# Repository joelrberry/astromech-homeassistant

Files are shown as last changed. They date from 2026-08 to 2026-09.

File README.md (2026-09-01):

# droidrefit — an offline-first astromech droid

Custom MicroPython firmware for a stationary R2-D2 display build. It runs
**standalone** — three front-panel buttons drive the dome servo, sound, and
dome lights (tap mode ▲ / ▼ to cycle reactions, hold to adjust volume, tap
sound for a clip), with a piezo buzzer for feedback. WiFi + **Home Assistant**
(pick a reaction from a dashboard) are an optional layer, off by default; hold
**Mode ▲ + Sound** ~5 s to set up WiFi. No RC transmitter.

> **Repo name is historical.** This started as a firmware swap on a *CyberBrick*
> ESP32-C3 core board. That board browned out under servo + NeoPixels + WiFi,
> so the project moved to a plain **ESP32** with an external 5 V supply and a
> from-scratch modular firmware. The reverse-engineering writeup from that first
> chapter is [docs/cyberbrick-origins.md](docs/cyberbrick-origins.md).

## What's here

| Path | What |
|---|---|
| [`droidrefit/`](droidrefit/) | the firmware — `app/` package, `lib/`, `boot.py`, `main.py`, `package.json` (OTA manifest) |
| [`tools/deploy.py`](tools/deploy.py) | one-command host→board sync (`mpremote`), also the initial-load tool |
| [`hardware/droidrefit-pcb/`](hardware/droidrefit-pcb/) | KiCad carrier board — sockets the ESP32 devkit + DFPlayer, one 5 V rail, USB-C in. [DESIGN.md](hardware/droidrefit-pcb/DESIGN.md) |
| [`docs/firmware.md`](docs/firmware.md) | **the firmware reference** — architecture, boot flow, control surfaces, OTA, recovery |
| [`docs/dfplayer.md`](docs/dfplayer.md) | DFPlayer Mini — SD-card layout, adding sound clips, the serial protocol |
| [`docs/cyberbrick-origins.md`](docs/cyberbrick-origins.md) | the original CyberBrick writeup (retired board, but the LED/MQTT approach carried forward) |
| [`docs/project-notes.md`](docs/project-notes.md) | running history — decisions, bugs found and fixed |

## Hardware (as-built)

Plain ESP32 devkit · one dome servo (GPIO18) · DFPlayer Mini + speaker
(GPIO16/17, BUSY GPIO4) · 4× WS2812 dome lights (GPIO5, via a `74AHCT1G125`
level shifter) · 3 buttons (GPIO32/33/25, pin↔GND) · piezo buzzer (GPIO27) ·
optional SSD1306 OLED (I2C, GPIO21/22) · a shared **5 V, 3 A+**
rail everything hangs off directly. The
[carrier PCB](hardware/droidrefit-pcb/DESIGN.md) (100×70 mm, USB-C in,
JLCPCB-assembled) makes that permanent; a breadboard works for bench work if
you power the ESP32 over its own USB.

## Quick start

```
pip install mpremote
python3 tools/deploy.py --wipe
```

`deploy.py` stages the copy in safe mode and SHA-verifies every file, retrying
over a flaky USB link; a failed run leaves the board at a safe REPL, and
re-running converges. `--stay` leaves it in safe mode; `--format` reformats
the flash (last resort).

> **After flashing, hard power-cycle the board** (pull power / press EN — not
> just a soft reset). `deploy.py` ends with a soft reset, but hardware timers,
> the UART, PWM, and singleton driver objects survive that; only a cold boot
> gives the clean state the firmware actually runs in.

It boots straight into the app, **offline**. Buttons: **tap** mode ▲ / ▼ to
cycle the 7 reactions, **hold** to raise / lower volume, tap Sound for a clip.
The buzzer beeps to confirm.

**To add Home Assistant:** hold **Mode ▲ + Sound** together ~5 s → the board
reboots into a WiFi AP **`R2-D2-XXXX`**. Join it from a phone, the setup page
opens, enter WiFi + a droid name (tick "Connect to Home Assistant" for the MQTT
broker fields), save. It reboots onto your network and HA auto-discovers it
over MQTT (Mode / Sound / Volume + diagnostic sensors). No always-on web panel;
the portal exits on its own after 5 min idle, or via its Cancel link.

**Updates go over USB** — after an edit, `python3 tools/deploy.py`. On-device
OTA exists but is opt-in, needs `network_enabled`, and — on a classic ESP32 —
a plain-HTTP LAN mirror (`ota_url`), because it can't TLS to GitHub while the
app runs. Detail in [docs/firmware.md](docs/firmware.md).

## Recovery

- `noboot.txt` at the flash root → boot straight to a clean REPL (`deploy.py` uses this)
- hold **Mode ▲ + Sound** ~5 s → reboot into the WiFi setup portal (auto-exits after 5 min idle)
- hold the ESP32 BOOT button ~10 s while running → factory reset (wipe config, reboot to portal)
- a crash-looping OTA build auto-rolls-back after 3 failed boots

## Credits

- **The droid** — [*Build-A-Droid: CyberBrick based robot kit*](https://makerworld.com/en/models/1549117-build-a-droid-cyberbrick-based-robot-kit)
  by **Neebick** on MakerWorld. That's the printed astromech this firmware
  drives; this repo is only the electronics + software, not the model.
  Licensed Creative Commons (see the model page for the exact variant and
  follow its attribution / non-commercial / share-alike terms).
- **`droidrefit/lib/umqtt/simple.py`** — vendored **unmodified** from
  [micropython-lib](https://github.com/micropython/micropython-lib/blob/master/micropython/umqtt.simple/umqtt/simple.py)
  (MIT). MicroPython ships no MQTT client.
- **`droidrefit/lib/dfplayer.py`** — a minimal DFPlayer Mini (YX5200) UART
  driver written for this project; the frame/checksum protocol is per the
  DFPlayer Mini datasheet and the widely-published community command tables,
  not copied from a specific library.
- **`droidrefit/lib/ssd1306.py`** — vendored from
  [micropython-lib](https://github.com/micropython/micropython-lib/blob/master/micropython/drivers/display/ssd1306/ssd1306.py)
  (MIT), SPI variant trimmed off.
- **[MicroPython](https://micropython.org/)** (MIT) — the runtime.
- The earlier CyberBrick chapter leaned on CyberBrick's own `/bbl` driver
  library — see [docs/cyberbrick-origins.md](docs/cyberbrick-origins.md#acknowledgments).

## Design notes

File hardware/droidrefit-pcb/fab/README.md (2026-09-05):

# droidrefit carrier PCB — fab package

Regenerated 2026-08-30 (USB-C power input; silkscreen labels de-overlapped).
2-layer, 100 × 70 mm, rounded
corners (r=3 mm), 4× M3 mounting holes. **DRC: 0 errors.**

## Order the bare board

Upload **`droidrefit-pcb-gerbers.zip`** (RS-274X gerbers + Excellon drill).

| Setting | Value |
|---|---|
| Layers | 2 |
| Dimensions | 100 × 70 mm |
| Thickness | 1.6 mm |
| Min track / clearance | 0.25 mm / 0.15 mm (well within any fab's spec) |
| Min drill | 0.3 mm |
| Copper | GND pour both layers, solid pad connection, ~32 stitching vias |

## SMD assembly (JLCPCB "Assembly")

Upload:
- **`droidrefit-pcb-BOM-JLC.csv`** — 14 line items, 20 designators
- **`droidrefit-pcb-CPL-JLC.csv`** — 20 placements, all top side

Every designator in the BOM matches one in the CPL and vice-versa (20 each).
The BOM lists designators comma-separated, **not** as ranges — JLC's parser
rejects `C5-C9` and wants `C5,C6,C7,C8,C9`. If you ever re-export from KiCad,
re-expand any ranges before uploading.
New since the first order: R8 (100 Ω, C22775), R9/R10 (4.7 kΩ, C23162) —
both JLC Basic parts, no extended fee.

This BOM/CPL is sized for JLC's **Economic PCBA** (no per-side setup fee).
Includes **J1, the USB-C receptacle** (SMD with 4 through-hole anchor posts —
JLC assembles these routinely). Basic parts: the 4 resistor values, 100 nF,
AO3401A, 5.1 k. Extended (~$3 setup each): LED, PTC fuse, JST-SH,
74AHCT1G125, USB-C.

**The 4 electrolytics (C1–C4) are deliberately NOT in these files.** SMD
aluminium electrolytic cans are reflow-temperature-restricted, so JLC only
runs them on Standard PCBA ($25/side setup + break-off rails). They are easy
to hand-solder (two large pads each) — see the hand-solder list below.

### Power input — USB-C, 5 V

J1 is a 16-pin USB-C receptacle. R6/R7 are the **5.1 kΩ CC pull-downs** that
tell any USB-C source "5 V device." Plug in any USB-C cable + phone charger /
power bank / laptop port. No PD chip — a 5 V/3 A charger delivers what the
board's ~2 A peak needs. (F1 PTC is 2 A-hold / 4 A-trip; Q1 is reverse-
polarity — mostly moot on USB-C but harmless.)

### Check rotations in JLC's preview

KiCad and JLC disagree on the 0° orientation of a few packages. JLC's upload
wizard draws each part on the board — rotate any that look wrong. Check:
**Q1** (SOT-23), **U3** (SOT-23-5), **D1** (LED cathode),
**J1** (USB-C mouth must face the board edge).

## Hand-soldered afterwards (NOT in the JLC files)

| Ref | Part | LCSC (ref) |
|---|---|---|
| C1, C4 | 1000 µF 10 V SMD electrolytic, CP_Elec_8×10.5 (D8) | C310838 |
| C2, C3 | 470 µF 10 V SMD electrolytic, CP_Elec_6.3×7.7 | C335982 |
| J2 | 1×3 2.54 mm pin header (servo) | C49257 |
| J5 | JST-PH 2.0 mm 2-pin (speaker) | C131337 |
| J6 | 1×4 2.54 mm pin header (front-panel buttons) | — TBD |
| J7 | 1×2 2.54 mm pin header (piezo buzzer) | — TBD |
| J8 | 1×4 2.54 mm pin header (OLED I2C) | — TBD |
| J9 | 1×4 2.54 mm pin header (UART0 access) | — TBD |
| U1 socket | **2× 1×15 female header, 2.54 mm** — buy 2 | — |
| U2 socket | **2× 1×8 female header, 2.54 mm** — buy 2 | — |

C1–C4 mount on the top-side silk outlines. Mind polarity: the **+** stripe
on the footprint marks pin 1; the can's marked stripe is the **−** terminal.

Then plug in: **ESP32 DevKit 30-pin** (your Elegoo one) and a **DFPlayer
Mini**. Loads on the connectors: dome servo → J2, R2 LED board via a Bambu
**XC016** JST-SH cable → J3, 4–8 Ω speaker → J5. Power: any USB-C cable → J1.

JP1 = bare solder-bridge pads, ships bridged **Signal→P1 / V+→P2 / GND→P3**
(corrected 2026-09-05 to match the dome board's actual measured pinout —
see DESIGN.md); cut & re-bridge only if a *different* LED board's SH1.0
order shows up.

Also hand-solder J6/J7/J8/J9 only if you're actually wiring up buttons /
buzzer / an OLED / a UART debug cable on this unit — they're optional.

## Known cosmetic DRC items (do not block fab)

- **7 silk-over-pad** — ref text on JP1, mounting holes, J5. JLC auto-clips.
- **1 footprint-lib mismatch on U2** — from a DFPlayer silk tweak. Right-click
  U2 → Update Footprint from Library, or ignore.
- Clearance rule is 0.15 mm in the project. If KiCad ever shows a 0.1988 mm
  flag at JP1, re-set Board Setup → Constraints → Min clearance = 0.15.
- DRC is **0 errors** as of 2026-09-05 (the earlier GND/NPX_P2 short was J9
  sitting in the JP1→J3 trace path — fixed by rerouting NPX_P2; J7 also
  moved out of the microSD card path). Only the cosmetic silk/lib warnings
  above remain.

## Files

```
droidrefit-pcb-gerbers.zip     → order the bare board
droidrefit-pcb-BOM-JLC.csv     → JLC assembly BOM (SMD only)
droidrefit-pcb-CPL-JLC.csv     → JLC placement file (SMD only, incl. USB-C)
droidrefit-pcb-BOM-full.csv    → everything incl. hand-solder parts
droidrefit-pcb-fab-preview.svg → quick visual check
*.g?? *.drl *-drl_map.pdf      → loose gerbers, drill, drill maps
```

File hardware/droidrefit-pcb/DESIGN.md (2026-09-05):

# droidrefit carrier PCB — design spec

A single carrier board that consolidates the whole "droidrefit" R2‑D2 build
(the plain‑ESP32 replacement for the retired CyberBrick) onto one PCB with a
proper shared 5 V rail. Replaces the breadboard described in `../../docs/firmware.md`.

**Decided (from Q&A 2026‑08‑29):**
- ESP32 = the existing Elegoo devkit, **socketed** on female headers (removable).
  Confirmed **30‑pin** (15/side), **24.5 mm** between the two pin banks →
  custom symbol `droidrefit:ESP32_DevKit_30pin` (DOIT DevKit v1 pinout).
- DFPlayer Mini likewise **socketed** on female headers →
  custom symbol `droidrefit:DFPlayer_Mini` (16‑pin, counter‑clockwise numbering).
- 5 V input via **USB-C** (changed from barrel jack 2026-08-30): `J1` =
  16-pin USB-C receptacle (`C2765186`) + `R6`/`R7` 5.1 kΩ CC pull-downs →
  any USB-C cable/charger/power bank gives 5 V. No PD chip. Fully SMD, so
  JLC assembles the power input too. F1 PTC now 1812 2 A-hold / 4 A-trip.
- NeoPixel data line goes through a level shifter (3.3 V → 5 V) —
  using the **single‑gate 74AHCT1G125** (SOT‑23‑5) rather than the SO‑14 quad;
  one buffer is all that's needed and it's a JLC catalog part.
- Fab: **JLCPCB assembly** — SMD passives / IC / FET / connectors placed by JLC;
  the two module sockets and any THT connectors hand‑soldered after.

## Device‑to‑device connections (verified against firmware + netlist)

Firmware‑proven (bench‑tested in `droidrefit/bench/test-boot*.py`):
- ESP32 GPIO17 → R2 1k → DFPlayer RX(2); DFPlayer TX(3) → ESP32 GPIO16
  (`main.py:157`, `UART(2, tx=Pin(17), rx=Pin(16))`)
- DFPlayer BUSY(16) → ESP32 GPIO4 direct, active‑low; ESP32 internal pull‑up
  only (`main.py:226` `Pin(4, Pin.IN, Pin.PULL_UP)`) — no external part
- ESP32 GPIO18 → servo signal (`main.py:150`, `PWM(Pin(18), freq=50)`)
- DFPlayer SPK_2(6)/SPK_1(8) → speaker connector J5

NeoPixel path (firmware written — `app/leds.py` — not yet bench-tested with real pixels):
- ESP32 GPIO5 → 74AHCT1G125 → R3 330 → JP1 → J3 (XC016) → LED board

All of the above are present in the schematic netlist.

## Status

- [x] Project + custom symbol library created, registered project‑scope.
- [x] Schematic drawn, wired, **ERC clean (0 errors)**. Netlist verified.
      (2 cosmetic "symbol doesn't match library copy" warnings on the two
      custom symbols — a create/round‑trip formatting diff, no netlist impact.)
- [x] Footprints assigned (provisional — see notes) + 3 custom footprints built
      (`droidrefit.pretty`): ESP32 30-pin socket (24.5 mm rows), DFPlayer socket
      (2.54 mm pitch, **15.24 mm / 0.6 in rows — confirmed from board spec**),
      NeoPixel bridge field.
- [x] Board created from schematic — 25 footprints, 20 nets.
- [x] Board outline 100×70 mm rounded-rect (3 mm corner radius), 4× M3
      mounting holes. **Moved 2026-09-05** to a symmetric 91×61 mm pattern
      (holes at 4.5 mm in from each edge: 4.5/4.5, 95.5/4.5, 4.5/65.5,
      95.5/65.5) — tighter into the corners so an M3 screw+washer clears
      J6/J2/J5 (the previous 7 mm-inset positions had MH2 courtyard-
      overlapping J5 and MH3/MH4 crowding J6/J2). Enclosure is 3D-printed
      and designed around wherever these land.
- [x] Placement cleaned — functional grouping, **0 DRC errors**, 0 courtyard
      overlaps. Remaining 27 DRC warnings = 23 silk-over-copper (ref text over
      THT pads, fix in silk-polish pass) + 4 custom-footprint metadata notes.
      Layout: U1 left · U2+C2+R2+J5 top · U3/R3/JP1/C4/J3 mid-right ·
      power (J1/F1/Q1/R1/C1) bottom-left · servo (C3/C8/J2) bottom-right.
- [x] **Routing — complete.** Design rules (0.2 clr / 0.25 trk / 0.6 via),
      `Power` netclass (0.8 mm) in the .kicad_pro. **B.Cu = GND pour.**
      - 13 nets hand-routed first (power front-end, both UARTs, NeoPixel
        section), then **Freerouting 2.1.0** autorouted the rest: +5V tree,
        SERVO_PWM, SPK_P/N, DFP_BUSY, and GND stitching vias.
      - Result: **120 tracks, 18 vias, every net routed**.
      - **Toolchain note:** Freerouting 2.3.0 needs Java 25; installed JRE is
        Temurin 21, so pinned to Freerouting **2.1.0** (`~/.kicad-mcp/freerouting.jar`).
        To use 2.3.x later, install a JRE 25+.
      - **B.Cu GND pour filled** (in KiCad, `B`) 2026‑08‑29 — ~6352 mm² of
        7000, all THT/SMD GND pads tie in (THT via thermal‑relief spokes,
        SMD via stitching vias). The 15 "via dangling" warnings cleared.
      - Clearance error **cleared**: it was the Default net class pinned at
        0.20 mm and Freerouting's +5V trace landing 0.1988 mm from JP1's GND
        pad. Not a physical problem — lowered the net‑class clearance to
        **0.15 mm** (JLCPCB standard is 0.127 mm), `.kicad_pro`
        `net_settings`. **DRC now 0 errors.**
      - **Remaining 12 DRC warnings, all cosmetic:** 1 lib_footprint_mismatch
        on U2 (silk fix — "Update Footprint from Library" clears it);
        4 custom‑footprint metadata notes; 7 silk‑over‑copper (ref text over
        pads — JLC auto‑clips; move the text in the silk‑polish pass).
- [x] **LCSC parts assigned** (via `jlcsearch.tscircuit.com` — the full JLC
      DB download 503'd). R4 removed; F1 settled on an **1812 2 A‑hold /
      4 A‑trip PTC** (C18198342) after a 2920/3 A version made the power
      corner un‑routable.
- [x] **USB-C power input** (2026-08-30): barrel jack → `J1` 16-pin USB-C
      (`C2765186`) + `R6`/`R7` 5.1 kΩ CC pull-downs. Routed (CC straight to
      R6/R7, VBUS up-and-over to F1, GND via the pours). **14 SMD line items.**
- [x] **GND pours both layers, refilled, solid pad connection**; ~32 grid
      stitching vias. **DRC: 0 errors.**
- [x] **DNP** on J2/J5/U1/U2/JP1 **+ C1–C4** (out of CPL). CPL hand-filtered to
      the SMD parts JLC places (incl. USB-C, which auto-excluded as "has THT pads").
- [x] **C1–C4 electrolytics moved to hand-solder (2026-08-30).** JLC flags SMD
      aluminium electrolytic cans as Standard-PCBA-only (reflow temperature);
      Standard adds $25/side setup + break-off rails (board → 100×80). Keeping
      Economic PCBA instead: C1–C4 set `dnp yes` + `in_pos_files no` in the sch,
      dropped from BOM-JLC/CPL-JLC, listed in `BOM-full.csv` as "hand-solder"
      and in the README hand-solder table. Silk outlines + refs still plotted.
- [x] **Fab package regenerated** (2026-09-05, final — via `kicad-cli`, same
      engine as the GUI, after the GUI finishing pass + GND stitching via) →
      `fab/`: gerbers zip, Excellon drill (+PDF maps), `BOM-JLC.csv`
      (14 lines / 20 desig) + `CPL-JLC.csv` (20), `BOM-full.csv`,
      `fab-preview.svg`, `2d-top.png`, `README.md`. Hand-crafted JLC formats
      preserved (`Designator,Mid X,Mid Y,Layer,Rotation` for CPL; C1–C4
      dropped from both JLC files, J6–J9 hand-solder). **R8/R9/R10 LCSC
      parts assigned**: R8 = C22775 (100 Ω 0603 1%, UNI ROYAL Basic),
      R9/R10 = C23162 (4.7 kΩ 0603 1%, UNI ROYAL Basic) — same UNI ROYAL
      `0603WAFxxxxT5E` family as R1–R7.
- [x] **ESP32 socket pinout VERIFIED** against the user's board photo
      (`fab/BoardImage.HEIC`, 2026-08-30) — both headers match the footprint
      exactly (standard DOIT DevKit v1). Added silk orientation markers to
      U1: "EN / ANT" one end, "VIN / devkit USB end" the other, pin-1 arrow.
      The devkit's own USB-C ends up on the same edge as the carrier's USB-C.
      U2 (DFPlayer) verified from the photo too: **µSD card slot is on the
      pin 8/9 (SPK/DAC) end**, opposite the "DFPlayer Mini" text / pin-1 /
      VCC end. Silk fixed — "microSD card slot this end" now on U2's south
      side (pin 8/9), pin-1 chevron on the north-left (VCC). U2 NOT rotated
      (keeps the UART pins facing the ESP32): the card ejects ~15 mm toward
      the board interior at the ~8 mm socket height — clear of everything
      until C1 (~30 mm away). Reach over the board to swap cards. Rotate U2
      180° only if edge-facing card access matters more than short UART runs.
- [x] **`J_BTN`/`J_BUZZER`/`J_OLED`/`J_UART` drawn and routed (2026-09-05,
      respin).** All four were fully speced in this doc from 2026-08-31 but
      never actually placed in the schematic/board until now. Added as
      `J6`/`J7`/`J8`/`J9` (plain refs, matching J2/J3/J5's own naming — not
      the descriptive `J_*` refs this doc used at planning time), each
      `Connector_Generic:Conn_01x0N` on `PinHeader_2.54mm` footprints, `dnp
      yes` + `Assembly: hand-solder` (matching J2/J5's treatment — these are
      2.54 mm headers meant for hand-soldering, not JLC-placed). Also added:
      `R8` (100 Ω, buzzer series resistor) and `R9`/`R10` (4.7 kΩ, I2C
      SDA/SCL pull-ups to 3V3) — both real SMD 0603s, JLC-placed like
      R1–R7. Board is now **32 footprints, 30 nets**. Placement: J6 bottom-
      left near U1 (button column), J7 mid-board near U3, J8+R9+R10 clustered
      top-left above U1 (OLED group), J9 in the open pocket at (83,40)
      between the JP1/U3/R3 cluster and J3. Routed by hand plus targeted
      Freerouting passes (`targetNets`) for the denser fan-outs, both refilled
      afterward — **zone refill after any routing change in this design is
      not optional**: a stale GND pour fill reads as dozens of phantom
      "0.0000 mm actual clearance" errors against copper added since the last
      fill, which resolve immediately on refill and are not real problems.
- [x] **JP1 default bridge corrected (2026-09-05).** The NeoPixel bring-up
      (see [[droidrefit-pcb-status]] / `droidrefit/bench/test-neopixel.py`)
      empirically confirmed the real dome-board connector order is
      **GND-pin1 / V+-pin2 / Signal-pin3** — the opposite of what this doc
      previously listed as the shipped default (DIN-P1/V+-P2/GND-P3, a
      pre-bring-up guess). Since JP1 exists specifically so a stock-built
      board doesn't need rework, re-mapped which J3 pin each bridge-field pad
      reaches (pad4↔J3/3, pad6↔J3/1, pad5↔J3/2 unchanged) so the **same-row,
      no-cut default bridge now delivers the confirmed-correct pinout**. See
      the corrected Connectors-table row below.
- [x] **DRC back to 0 errors (2026-09-05).** The residual GND/NPX_P2 short
      turned out to be J9 sitting in the path of the JP1→J3 NeoPixel-bundle
      traces — the straight NPX_P2 run at y=42 was clipping J9's GND pad at
      (83,42.54). Rerouting NPX_P1/P3 around J9 by hand had left P2 (which I
      never touched, its net assignment didn't change) still straight
      through. Fix: let Freerouting route NPX_P2 (as it had already done
      cleanly for P1), which also settled the JP1 bridge-field zone sliver.
      **Also moved J7** — the auto-placer had jammed it at (52,32), directly
      in the DFPlayer's microSD card insertion/ejection path (~3 mm south of
      the SD-slot edge, pins tall enough to foul a card or a plugged-in
      wire). Relocated to (46.25,40), west of the card corridor, buzzer wire
      now exits near the left edge; BUZZER_PWM re-routed. **Board is now
      0 DRC errors + the same 12 pre-existing cosmetic warnings.**
- [x] **J1 USB-C part corrected to match the footprint (2026-09-05).** The
      KiCad footprint `USB_C_Receptacle_HCTL_HC-TYPE-C-16P-01A` is drawn for
      LCSC **C2894897** (HCTL — the KiCad lib cites its datasheet), but the
      BOM was ordering **C2765186** (SHOU HAN "TYPE-C 16PIN 2MD"), a
      different brand whose shield-tab/mounting-post positions don't match —
      showed up as J1 "not lining up with the holes" in JLC's preview.
      Swapped the BOM to C2894897. If it's ever out of stock, the
      jenschr/USB-C-Connectors KiCad repo has per-LCSC-part 16P USB-C
      footprints to match whatever's available.
- [x] **R8/R9/R10 LCSC parts assigned (2026-09-05).** R8 = C22775
      (100 Ω 0603 1%, UNI ROYAL `0603WAF1000T5E`, JLC **Basic**),
      R9/R10 = C23162 (4.7 kΩ 0603 1%, UNI ROYAL `0603WAF4701T5E`, JLC
      **Basic**) — added as `LCSC`/`MPN`/`Manufacturer`/`JLCPCB_Assembly`
      props in the sch, same UNI ROYAL family as R1–R7, both Basic so no
      extended-part fee. BOM-JLC / CPL-JLC / BOM-full regenerated.
- [ ] Silk polish (7 ref-text-over-pad warnings) + U2 footprint re-sync — cosmetic, pre-existing.
- [ ] Order: bare board from gerbers zip; **Economic** SMD assembly from
      BOM-JLC + CPL-JLC (check rotations in JLC's preview — esp. Q1/U3/D1/J1);
      hand-solder C1–C4 + J2/J5/J6/J7/J8/J9 + 2 module sockets; plug in ESP32
      + DFPlayer.

### Provisional footprint notes
- Q1 = SOT-23 placeholder; real part is Id ≥ 6 A → likely DPAK/SOT-89.
- C1/C4 = CP_Elec_8x10.5, C2/C3 = CP_Elec_6.3x7.7 — verify against the actual
  1000 µF/470 µF 10 V parts chosen.
- J1 = CUI PJ-102AH horizontal (has a switch pad; symbol is 2-pin).

## As‑built net names (schematic)

`+5V` `+3V3` `GND` · `VBUS_IN` (jack→fuse) · `VFUSED` (fuse→P‑FET source) ·
`SERVO_PWM` (IO18) · `NPX_IN` (IO5→buffer) · `NPX_DATA_5V` (buffer→R3) ·
`NPX_DATA` (R3→J3/J4) · `ESP_TX2` (IO17→R2) · `TX2_DFP` (R2→DFP RX) ·
`RX2_DFP` (IO16↔DFP TX) · `DFP_BUSY` (IO4↔DFP BUSY, direct) ·
`SPK_P`/`SPK_N` (DFP pins 6/8 → J5) · `LED_A` (R5→D1).

## Firmware pin map (source of truth: `droidrefit/main.py`, `docs/firmware.md`)

| ESP32 GPIO | Net | Goes to | Notes |
|---:|---|---|---|
| 17 | `TX2_DFP` | DFPlayer RX (pin 2), via 1 k series  | 1 k is the standard DFPlayer noise‑reduction resistor |
| 16 | `RX2_DFP` | DFPlayer TX (pin 3), direct | DFPlayer TX idles ~3.3 V, safe |
| 4 | `DFP_BUSY` | DFPlayer BUSY (pin 16), direct | active‑low; firmware sets the ESP32 internal pull‑up (`Pin.PULL_UP`) — no external resistor, matches the proven bench wiring |
| 18 | `SERVO_PWM` | Servo connector signal | 50 Hz hobby servo |
| 5 | `NPX_IN` | 74AHCT1G125 A (pin 2) | shifter input. GPIO5 kept per `docs/firmware.md` (user decision 2026‑08‑29) — it's a boot‑strapping pin (internal pull‑up, fine in practice); accept a possible brief LED flash at power‑on. |
| — | `NPX_DATA` | 74AHCT125 Y1 (pin 3) → 330 Ω → NeoPixel connector(s) | 5 V logic out |
| 32 | `BTN_MODE_UP` | J_BTN pin 2 → button → GND | firmware internal pull‑up, active‑low; no external part |
| 33 | `BTN_MODE_DN` | J_BTN pin 3 → button → GND | " |
| 25 | `BTN_SOUND` | J_BTN pin 4 → button → GND | " — tap = sound; Mode▲+Sound 5 s = WiFi setup |
| 27 | `BUZZER` | → piezo → GND (J_BUZZER) | `machine.PWM` UI feedback. Bare piezo disc + ~100 Ω series R for a quiet beep; option: 2N7002 low‑side + piezo from +5 V for louder |
| 21 | `I2C_SDA` | J_OLED pin 3 → SSD1306 SDA | ESP32 default I2C SDA. Firmware auto‑detects the OLED (`i2c.scan()`); absent = no display task |
| 22 | `I2C_SCL` | J_OLED pin 4 → SSD1306 SCL | ESP32 default I2C SCL |
| 1 | `UART0_TX` | J_UART pin 3 | REPL / boot console TX. Also on the devkit's onboard Micro‑USB → do **not** connect a USB‑TTL cable to J_UART and plug the devkit's USB at the same time (bus contention) |
| 3 | `UART0_RX` | J_UART pin 4 | REPL / boot console RX |
| VIN | `+5V` | shared rail | devkit's onboard LDO feeds its own logic |
| 3V3 | `+3V3` | J_OLED pin 1 (SSD1306 VCC) | now used — the devkit's onboard regulator (AMS1117, fed from +5V) powers the ~20 mA OLED. R4 pull‑up still removed (redundant with the firmware internal PU). If no OLED is fitted, 3V3 is simply unloaded. |
| GND | `GND` | — | |

Unused 74AHCT125 inputs (A2..A4) tied to GND; unused `/OE2../OE4` tied to GND;
`/OE1` tied to GND (buffer 1 always enabled).

## Power tree

```
J_PWR (5V barrel, centre +)
  └─ F1  PTC resettable fuse (Ihold ≥ 3 A)
       └─ Q1  P‑FET reverse‑polarity protection (high‑side, Id ≥ 6 A, low Rds(on))
            └─ +5V rail ──┬─ C_BULK 1000 µF / 10 V (low‑ESR) + 100 nF
                          ├─ ESP32 VIN            (+ 100 nF)
                          ├─ DFPlayer VCC         (+ 470 µF + 100 nF, close to socket)
                          ├─ Servo connector V+   (+ 470 µF + 100 nF, close to connector)
                          ├─ NeoPixel connector V+(+ 1000 µF + 100 nF, close to connector)
                          ├─ 74AHCT125 VCC        (+ 100 nF)
                          └─ PWR LED + 2 k        (green, "rail live")
```

Rail sizing target: ~2 A realistic peak, 3 A+ supply (see `docs/firmware.md`).
Trace/pour: dedicated +5V and GND copper pours, ≥ 2 mm equivalent for the
servo + NeoPixel + DFPlayer branch; wide fill everywhere else.

## Connectors

| Ref | Type | Pins | For |
|---|---|---|-----|
| J_PWR | DC barrel jack 2.1 mm, centre + | +, − | 5 V input |
| J_ESP | 2 × 1×19 female socket, 2.54 mm | full devkit | ESP32 devkit — **row spacing TBD, must measure the physical Elegoo board** |
| J_DFP | 2 × 1×8 female socket, 2.54 mm | DFPlayer Mini 16‑pin | row spacing **15.24 mm (0.6 in)** — confirmed |
| J_SERVO | 1×3 header, 2.54 mm, friction lock | SIG / +5V / GND | dome servo — confirm lead order before crimping |
| J3 (J_NPX) | JST‑SH 1.0 mm 3‑pin (SMD) | pins → JP1 P1/P2/P3 | mates the **Bambu XC016** cable (300 mm straight‑through JST‑SH 1.0 3‑pin) to the droid's existing multi‑LED board |
| JP1 | pin‑order **solder‑bridge field** (custom)| DIN/V+/GND ↔ P1/P2/P3  | maps DATA/+5V/GND to any of the 3 connector pins. **Ships bridged Signal‑P1 / V+‑P2 / GND‑P3** (corrected 2026‑09‑05 to match the empirically‑confirmed dome pinout — see Status); cut & re‑bridge only if a *different* LED board's SH1.0 order shows up. V+ = **+5V** (confirmed). |
| J_SPK | JST‑PH 2.0 mm 2‑pin | SPK+ / SPK− | 4–8 Ω speaker, DFPlayer pins 6 & 8 — differential, do **not** ground |
| J_BTN | 1×4 header, 2.54 mm | GND / IO32 / IO33 / IO25 | front‑panel buttons: mode ▲ (IO32), mode ▼ (IO33), sound (IO25). Each wires between its signal pin and GND; firmware internal pull‑up, **no external resistors**. Tap = cycle / hold = volume; Mode ▲ + Sound 5 s = WiFi setup. |
| J_BUZZER | 1×2 header, 2.54 mm (or onboard piezo pads) | IO27 / GND | piezo buzzer for UI feedback. Direct off IO27 through ~100 Ω for a quiet beep; footprint should also allow a 2N7002 low‑side driver + piezo from +5 V. Skipped in firmware when `buzzer_enabled` is false. |
| J_OLED  | 1×4 header, 2.54 mm | 3V3 / GND / IO21 / IO22 | SSD1306 128×64 I2C status display (addr 0x3C). ~20 mA off **3V3**, not +5V. Firmware auto‑detects — no display = no cost. Shows name/mode/volume/net while running, and the AP name+password+URL while the setup portal is up. Pin order matches the common 4‑pin SSD1306 module (GND/VCC/SCL/SDA varies by module — confirm silk before crimping). Add 4.7 kΩ SDA/SCL pull‑ups to 3V3 on the board (most modules already have them → ~2.3 kΩ effective, still fine; keeps a bare panel working). |
| J_UART  | 1×4 header, 2.54 mm | 3V3 / GND / IO1(TX0) / IO3(RX0) | serial console / `deploy.py` for a **boxed unit** without opening it — plug a USB‑TTL cable here (leave its 5V/VCC lead off; 3V3 pin is only a reference/optional). No onboard USB‑serial chip on the carrier; the carrier's USB‑C is power‑only. **Never** use this and the devkit's own Micro‑USB at once. No auto‑reset wiring → press EN / power‑cycle to reset. |

### Updating a boxed unit

The carrier's USB‑C is **power only** — no data lines, no USB‑serial chip. Once
the droid is in its box there are three ways in:

1. **`J_UART`** + a USB‑TTL cable — `deploy.py` / serial without opening the box.
2. **Devkit Micro‑USB** — reachable only via a box cutout; the auto‑reset /
   auto‑flash path.
3. **OTA** (`app/ota.py`, opt‑in) — wireless once the droid is on WiFi with an
   `ota_url` mirror set. The "never touch it again" path.

## DFPlayer Mini pinout reference (16‑pin, for J_DFP wiring)

1 VCC · 2 RX · 3 TX · 4 DAC_R · 5 DAC_L · 6 SPK_2 · 7 GND · 8 SPK_1 ·
9 IO_1 · 10 GND · 11 IO_2 · 12 ADKEY_1 · 13 ADKEY_2 · 14 USB_DP · 15 USB_DM · 16 BUSY

Only VCC/RX/TX/SPK_2/GND/SPK_1/BUSY are wired; DAC/IO/ADKEY/USB left unconnected
(with `no_connect` flags).

## BOM (JLCPCB — exact LCSC part numbers assigned during part selection)

| Ref | Value / part | Package  | JLC tier (target) |
|---|---|---|---|
| U3 | 74AHCT1G125 (single-gate buffer) | SOT‑23‑5 | Extended |
| Q1 | P‑MOSFET, −20 V, Id ≥ 6 A, low Rds | SOT‑23 / DPAK | Basic |
| F1 | PTC resettable fuse, Ihold ≥ 3 A | 1812 | Basic |
| D1 | LED, green | 0603 | Basic |
| C_BULK, C_NPX  | 1000 µF / 10 V, low‑ESR | SMD can  | Extended |
| C_DFP, C_SERVO | 470 µF / 10 V | SMD can  | Extended |
| C1..C5 | 100 nF X7R | 0603 | Basic |
| R_DFP | 1 kΩ | 0603 | Basic |
| R_NPX | 330 Ω | 0603 | Basic |
| R_LED | 2 kΩ | 0603 | Basic |
| R_GATE (R1) | 100 kΩ (P‑FET gate) | 0603 | Basic |
| J_PWR | DC barrel jack 2.1 mm | THT | Extended |
| J_NPX | JST‑SH 1.0 mm 3‑pin | SMD | Basic/Extended |
| J_SPK | JST‑PH 2.0 mm 2‑pin | THT | Basic |
| J_ESP, J_DFP, J_SERVO, J_NPX2 | 2.54 mm sockets/headers | THT | hand‑solder, not JLC placed |
| MH1..MH4 | M3 mounting holes | — | — |

## Board

- ~2‑layer, size follows the devkit footprint + a strip for power/DFPlayer/connectors.
  Rough guess 70 × 60 mm, finalised after placement.
- Layer 1: signal + GND pour. Layer 2: +5V pour where the branch runs, GND elsewhere.
- 4 × M3 mounting holes, corners.
- Silk: label every connector, mark J_PWR polarity, mark J_SERVO pin 1, mark
  J_NPX / J_NPX2 pin 1 with a "verify ring order" note.

## Open items to resolve before routing

1. **Elegoo devkit variant** — 30‑pin vs 38‑pin, and row spacing (0.9 in vs 1.0 in).
   Physically measure the board on hand. Affects J_ESP footprint + the GPIO the
   pins land on.
2. **DFPlayer socket row spacing** — RESOLVED: 15.24 mm (0.6 in), 2.54 mm pitch.
3. **J_SERVO pin order** — match the dome servo's existing 3‑pin lead.
4. **NeoPixel SH1.0 pin order** — RESOLVED, twice: first as a build‑time
   solder‑bridge (JP1) since the LED board couldn't be probed, then
   (2026‑09‑05) the bring‑up on real hardware actually measured it —
   **Signal/V+/GND**, not the DIN/V+/GND guess this item originally recorded
   — and JP1's default bridge was corrected to match (see Status). J3
   gender: XC016 is a plug‑both‑ends cable; J3 must be the mating SH1.0
   **top/side‑entry SMD socket** — entry direction still unconfirmed at
   layout, unrelated to the pin-order fix above.
5. RESOLVED — spare GPIOs are broken out as `J_BTN` (IO32/33/25 + GND) for the
   three front-panel buttons; firmware drives them with internal pull-ups.

## Build sequence (KiCad MCP)

1. `create_project` at this path.
2. Schematic: place J_ESP (as ESP32 devkit symbol), J_DFP, U1, Q1/F1 power
   front‑end, connectors, passives. Wire per the pin map above. ERC.
3. Assign footprints + LCSC parts (download JLC parts DB first).
4. `create_board_from_schematic`, board outline, place, pours, route, DRC.
5. Gerbers + drill + BOM + CPL for JLCPCB.

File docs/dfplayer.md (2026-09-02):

# DFPlayer Mini — how the droid uses it

Reference for the audio module: the SD-card layout, how to add clips, and what
the serial protocol can and can't do. Driver: [`droidrefit/lib/dfplayer.py`](../droidrefit/lib/dfplayer.py).
Playback logic: [`droidrefit/app/sound.py`](../droidrefit/app/sound.py).

## The module

"DFPlayer Mini" is a **family** of pin-compatible modules built around different
chips — YX5200, YX5300, MH2024K-24SS, GD3200B, JL AB23A, and more. They share
the frame protocol but **differ in which query commands work and how replies
are framed**. Anything past "play a track / set volume / read BUSY" should be
treated as module-specific.

This build talks to it over **UART2 at 9600 baud** (`GPIO17`→RX, `GPIO16`←TX,
1 kΩ in series on TX) and reads the **BUSY pin** (`GPIO4`, active-low) for
"is a track playing". That's the whole interface — deliberately minimal,
because it's the part that behaves the same on every module.

## SD card layout

- **FAT32**, card ≤ 32 GB.
- Numbered folders at the root: `01`, `02`, … `99` (two digits).
- Files inside: `001.mp3`, `002.mp3`, … up to `255.mp3` (three digits,
  zero-padded). A leading human name after the number is fine (`003 happy
  beep.mp3`) — the module keys off the leading number.
- **No gaps** in the numbering within a folder.
- Some clone chips index files by **the order they were copied to the card**,
  not by filename. If playback order matters, copy the files in numeric order,
  or run `fatsort` on the card afterwards.

The droid's folders:

| Folder | `SOUND_FOLDERS` name | Mood |
|---|---|---|
| `01` | `chat` | idle chatter / beeps |
| `02` | `gen` | general / misc |
| `03` | `happy` | pleased, excited |
| `04` | `leia` | the Leia message |
| `05` | `sad` | worried, mournful |
| `06` | `scream` | alarm / distress (also the `system_crash` cue) |
| `07` | `whistle` | short whistles |

## How playback works

`app/sound.py`:

```python
SOUND_FOLDERS = {"chat": (1, 18), "gen": (2, 19), "happy": (3, 7),
                 "leia": (4, 3), "sad": (5, 4), "scream": (6, 3),
                 "whistle": (7, 3)}
```

`{name: (folder_number, file_count)}` — **the counts are hard-coded.** A trigger
(button, MQTT, or `mood_sound_task`) calls `play_random_in_folder(name)`, which
picks `track = random(1..count)` and sends **play-folder-track** (`0x0F`) with
that `folder, track`. `busy_monitor_task` then watches BUSY to know when it
finished.

**Per-mood audio.** Each mood has a Home Assistant `Audio` dropdown (Off + these
7 categories) and an `Audio Repeat (s)` slider. `sound.mood_sound_task` plays a
random track from the selected category when the mood is entered, and every
`audio_gap` seconds after while the mood holds — subject to BUSY, and never over
a user-picked clip. No firmware mood→folder table: every mood ships `Off`,
including `system_crash` (set its dropdown to `scream` for the old crash cue).

### Adding clips to a folder

1. Copy the new file(s) into the folder as the next sequential number
   (`03/008.mp3`, `03/009.mp3`, …).
2. Bump that folder's count in `SOUND_FOLDERS` (`"happy": (3, 7)` → `(3, 9)`).
3. `python3 tools/deploy.py`.

One line changed, one flash. The folder *numbers* never change, so the mapping
above is stable.

## Serial protocol

Frame: `7E FF 06 <cmd> <feedback> <p1> <p2> <ck_hi> <ck_lo> EF` — full detail in
the `lib/dfplayer.py` header.

### Commands the firmware sends

| Cmd | Meaning | Used for |
|---|---|---|
| `0x0C` | reset | boot diagnostics (`player.reset()`) |
| `0x09` | select storage device | `select_tf_card()` at boot (p2 = `0x02` = TF) |
| `0x06` | set volume 0–30 | `set_volume()` |
| `0x0F` | play folder/track (p1 = folder, p2 = track) | every sound trigger |

### Query commands — available, **not used here**

| Cmd | Returns | Why unused |
|---|---|---|
| `0x4F` | total folder count on the card | not needed — folders are fixed |
| `0x47` / `0x48` | total file count (TF vs USB — **swaps by module**) | grand total, not per-folder |
| `0x4E` | files in the **current** folder | only valid *after* a track from that folder is selected, and unreliable on clones |
| `0x42` | play status (stopped / playing / paused) | BUSY pin covers it |
| `0x43` | current volume | firmware is the source of truth (`core.state["volume"]`) |
| `0x46` | firmware version | — |
| `0x4C` | index of the track currently playing | — |

### Replies

The module sends 10-byte reply frames — ACK (`0x41`, only if the feedback bit
is set), errors (`0x40` + a code), query answers, and **unsolicited** messages:
track-finished (`0x3D` on TF, with the finished track's index), card
inserted / removed (`0x3A` / `0x3B`), init after reset (`0x3F`).

`dfplayer._log_reply()` reads and **logs** whatever comes back right after a
command (best-effort, ~50 ms window) — turn the debug switch on to see it while
bench-testing wiring. **Nothing in the firmware acts on replies.**

## Things the DFPlayer can't do

- **No file listing, no names, no manifest.** It plays by number only.
- **No "does track N exist" query.** You find out by playing it and getting
  error reply `0x40` with code `0x06` ("track not found").
- **No reliable cross-module "track finished" event** — hence the BUSY pin.

## If the hard-coded counts ever become a maintenance pain

Three ways to make folders self-sizing, in rough order of robustness. **All of
them first require upgrading `dfplayer.py` to parse reply frames** (send a
query, read the specific 10-byte answer, return the value) — it only logs them
today.

1. **Overshoot-and-retry.** Drop the counts entirely. Pick a random index in a
   generous range, play it; if `0x40`/`0x06` comes back, retry lower and cache
   the folder's real ceiling. Folders grow to any size, zero bookkeeping;
   costs an occasional ~100 ms retry.
2. **Boot-time `0x4E` probe.** At startup, silently (volume 0) play track 1 of
   each folder, query `0x4E`, cache the count; fall back to configured defaults
   if the module doesn't answer. No runtime cost; depends on flaky `0x4E`.
3. **Counts in `config.json`.** Move `SOUND_FOLDERS` counts into config so
   adding files is a REPL command, not a reflash. Simplest; still manual.

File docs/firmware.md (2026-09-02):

# Firmware (`droidrefit/`)

MicroPython for a plain **ESP32** (stock `ESP32_GENERIC`, tested on v1.29)
driving an astromech droid: one dome servo, a DFPlayer Mini for sound, and a
4-pixel WS2812 dome-light string. **Offline-first** — it boots and runs
standalone, controlled by three front-panel buttons (mode ▲ / mode ▼ / sound).
WiFi + Home Assistant (MQTT) are an optional layer, **off by default**; hold the
Sound button ~5 s to bring up a WiFi setup portal. Updates are over USB
(`tools/deploy.py`).

Replaces the retired CyberBrick core board (see
[cyberbrick-origins.md](cyberbrick-origins.md) and
[project-notes.md](project-notes.md)) — the reason for the move was a real
brownout: servo + LEDs + WiFi through CyberBrick's onboard regulation. The fix
is an external 5 V rail everything hangs off directly; the
[carrier PCB](../hardware/droidrefit-pcb/DESIGN.md) makes that permanent.

## Hardware

| Signal | GPIO | Notes |
|---|---|---|
| Dome servo PWM | `GPIO18` | 50 Hz, `machine.PWM` |
| DFPlayer UART2 TX / RX | `GPIO17` / `GPIO16` | 9600 baud |
| DFPlayer BUSY | `GPIO4` | active-low, playback-finished detect |
| NeoPixel data | `GPIO5` | 4 pixels; via a `74AHCT1G125` 3.3→5 V shifter on the PCB (often fine direct on a short bench run). Skipped entirely when `leds_enabled` is false |
| Button: mode ▲ / mode ▼ / sound | `GPIO32` / `GPIO33` / `GPIO25` | each pin↔GND, internal pull-up, active-low. PCB header `J_BTN` |
| Piezo buzzer | `GPIO27` | `machine.PWM`; pin↔piezo↔GND. Skipped when `buzzer_enabled` is false |
| OLED (SSD1306 128×64) | `GPIO21` SDA / `GPIO22` SCL | I2C0 @ 400 kHz, addr 0x3C/0x3D. Auto-detected — absent = no display task. VCC off **3V3** |
| Factory-reset | `GPIO0` | the devkit BOOT button, held ~10 s while running |

Power: **5 V, 3 A+** into the rail. Servo, DFPlayer and pixels wire straight to
it; the ESP32 taps it at `VIN`. Realistic combined peak ~2 A (servo stall
~1 A + WiFi bursts ~0.5 A + 4 pixels white ~0.24 A + amp). The carrier board
takes 5 V over USB-C (16-pin receptacle + 5.1 kΩ CC pull-downs = "5 V device").
No 12 V input without adding a buck + bumping the bulk caps to 16–25 V.

## Getting it onto a board

```
pip install mpremote
python3 tools/deploy.py --wipe     # first load
python3 tools/deploy.py            # after an edit
```

`deploy.py` holds the board in **safe mode** for the whole copy (`noboot.txt`
+ reset, so the app isn't running and nothing competes for the flaky USB
link), copies `app/`, `lib/`, `boot.py`, `main.py` **one file at a time,
SHA-256-verifying each on the device and re-copying on mismatch**, then imports
every module. Only when all of that passes does it remove `noboot.txt` and
reboot into the app. A failed or interrupted run leaves the board safely at
the REPL — re-run and it converges (only unverified files are re-sent). It
never writes `/config.json`.

- `--stay` — deploy but leave the board in safe mode at the REPL.
- `--format` — reformat the flash filesystem first (last resort; also wipes
  `/config.json`). Use only if verified copies keep failing on the *same*
  file, which points at a corrupt filesystem rather than a flaky cable.

**Bringing up WiFi / Home Assistant** — hold the Sound button ~5 s (or do a
factory reset). The board reboots into a WiFi AP `R2-D2-XXXX` (WPA2, sticker
password); join it from a phone, the setup page auto-opens, enter WiFi + a
droid name, tick "Connect to Home Assistant" for the MQTT fields, save. It
reboots with `network_enabled = true` and connects. Until then it runs fully
offline on the buttons.

For bench work, skip the portal: create `app/config_baked.py` (gitignored,
copy `config_baked.py.example`) with your WiFi/MQTT — set `network_enabled: true`
in it to auto-connect.

## Architecture

`/boot.py` (adds `/lib` to the path) → `/main.py` (recovery checks, then
`from app.main import run`) → the `app` package. Module graph is a DAG
(MicroPython has no circular imports):

```
hw, core, config, version   leaves
sound  -> core, hw           servo -> core, sound, hw     leds -> core, hw
diag   -> core               ota   -> core, version      fx -> core, hw
oled   -> (machine, lib/ssd1306)      display -> core, oled
control -> core, sound, servo         buttons -> core, hw, control, fx
net    -> core, sound, servo, diag, ota, control
provisioning -> config, oled          main -> everything
```

Shared state lives in `core` (`state`, `servo_state`, `conn`, `link_state`,
`cfg`). Feature modules do `from app import core` and read `core.X` at call
time — never `from app.core import cfg` (it's `None` until `core.init()`).
Every long-lived task runs under `core.supervise()`, which restarts just that
task on a crash and counts restarts (surfaced in diagnostics).

`app/main.py` `main()`: if `/portal.flag` exists → run the setup portal (blocks,
reboots on save). Else `core.init(cfg)`, import modules, and — only when
`cfg["network_enabled"]` — connect WiFi (+ MQTT if `mqtt_enabled`). Then
`ota.confirm()` and gather the task set: `servo`, `led`, `busy_monitor`,
`mood_sound`, `button`, `reset_button`, `log` always; the MQTT tasks only when
networked.

### Recovery hatches (root `/main.py`, self-contained — no `app` import)

| Hatch | Trigger | Effect |
|---|---|---|
| Safe mode | `noboot.txt` present at FS root | print a banner, don't start the app → clean REPL (`tools/deploy.py` uses this) |
| Ctrl-C | any time the app / asyncio loop is running | drops to the REPL (not a boot-time countdown — that was removed as a stray byte on the serial line could trip it) |
| OTA rollback | `/ota.flag` present and boot count > 2 | restore `/bak` (pre-update files), reboot the old build |
| Setup portal | **Mode ▲ + Sound** held ~5 s | write `/portal.flag`, reboot → AP portal. Self-recovers after 5 min idle; a Cancel link exits without saving |
| Factory reset | hold `GPIO0` ~10 s while running | scream, wipe `/config.json`, write `/portal.flag`, reboot → portal |

## Config store — `app/config.py`

`/config.json` at the FS root is the live config, written by the portal.
`load()` **always** returns a normalised dict — no file just means offline
defaults (`network_enabled = false`); `save()` is atomic; `wipe()` clears it.
Key flags: `network_enabled` (gate on all WiFi/MQTT), `mqtt_enabled`,
`leds_enabled` (skip the NeoPixel/RMT path), `buzzer_enabled`. `topic_prefix`
(a slug of the droid name, or `r2d2`) is the single per-droid identity — MQTT
client id, the whole topic tree, every HA `unique_id`, the HA device id.

## Control — buttons (`app/buttons.py` → `app/control.py`)

Three buttons on `GPIO32/33/25`, pin↔GND, internal pull-up, active-low —
`button_task` polls at 50 ms:

- **mode ▲ / mode ▼** — **tap** (<0.5 s) steps `core.state["mode"]` through
  `control.MODE_CYCLE` (the 7 resting modes; `system_crash` is HA-only),
  wrapping. **Press-and-hold** (>0.5 s) = volume ±1 every 0.25 s while held.
- **sound** — tap (<0.8 s) fires a random sound category.
- **Mode ▲ + Sound** held ~5 s — the config-portal chord (deliberate; a lone
  button can't trigger it).

`control.apply_mode / apply_sound / apply_volume / nudge_volume / cycle_mode`
are the single code path — buttons, MQTT and the portal all call them.

**Feedback:** `app/fx.py` drives a piezo on `GPIO27` (`machine.PWM`) for a
volume tick (pitch tracks the level), a mode-change blip, the portal-entry
chirp, and save/error tones. The dome NeoPixels also encode the current mode
(`leds.LED_REACTIONS`).

## Control — Home Assistant *(only when `network_enabled`)*

MQTT auto-discovery publishes on connect. Topics are `<prefix>/…`:

| Entity | Command | State |
|---|---|---|
| Mode (select, 8) | `<prefix>/command` `{"mode": …}` | `<prefix>/mode/state` |
| Sound (select, 7 folders + idle) | `<prefix>/sound/command` `{"sound": …}` | `<prefix>/sound/state` |
| Volume (number 0–30) | `<prefix>/sound/volume/set` | `<prefix>/sound/volume/state` |
| Debug logging (switch) | `<prefix>/debug/set` | `<prefix>/debug/state` |
| Firmware (update) — *only if `ota_url` set* | `<prefix>/ota/set` `install` | `<prefix>/ota` |
| Heartbeat (sensor) | — | `<prefix>/heartbeat` (60 s, `expire_after` 180) |
| Diagnostics (sensors) | — | `<prefix>/diag` JSON + `<prefix>/diag/reset` |
| Mood tuning (numbers + `audio` select + reset button, one HA sub-device per mood) | `<prefix>/tune/<mood>/<knob>/set`, `<prefix>/tune/<mood>/reset` (`reset`) | `<prefix>/tune/<mood>/<knob>` (retained) |

`<prefix>/log` carries `log_always()` output (queued and drained one line per
~20 ms so bursts don't truncate on the socket). Availability is re-asserted
every heartbeat so a stray LWT `offline` self-heals.

MQTT commands land via `control.apply_*` — same path as the buttons.

There is **no always-on web control panel** — it was removed (its accept loop
wedged after WiFi blips and leaked sockets). The only web surface is the
first-run setup portal (`app/provisioning.py`), reached on demand.

### Tuning moods from Home Assistant

A curated set of per-mood knobs — enough to reshape a mood without a reflash,
not the full parameter surface. Each mood is published as its **own HA
sub-device** (`"<droid> <Mood>"`, linked to the droid via `via_device`), so HA
auto-generates a **separate card per mood**. Changes take effect **within one
behaviour tick** (`core.tune_gen` is bumped; `servo_task` / `led_task` rebuild
the current behaviour), and the new value is echoed back to HA immediately. The
`config.json` write is **debounced ~1.5 s** past the last change — a slider drag
is one flash write, not dozens, and the MQTT receive loop never blocks on flash
(that stall used to flag the link down and delay the HA echo by a full
`connection_watchdog` cycle).

| Knob | Range (stock) | Effect |
|---|---|---|
| Speed | 0–100 (50) | multiplies the mood's cruise speed by `knob/50`, clamped to 15–300 °/s |
| Restlessness | 0–100 (50) | scales `_Wander`/`_Dart` wait times by `50/knob` (higher = twitchier), floored at 200/400 ms |
| LED Bright | 0–200 (100) | multiplies every pixel's brightness for that mood by `knob/100`, clamped to 0–1 |
| Audio | select: `off` + the 7 sound categories (`off`) | a random clip from that category plays when the mood is entered — see below |
| Audio Repeat (s) | 0–300 (0) | 0 = once on entry; N = also replay every ~N s (jittered) while the mood holds |
| Duration (s) | 0–300 (0) | 0 = permanent; N = auto-revert to the previous mode after N s. `system_crash` shows 10 (its stock revert) until changed |

Which knobs each mood gets depends on its behaviour class: `_Wander` /
`_Dart` moods (standby, awake, excited, alert) get Speed + Restlessness;
`_Sweep` (surveillance) and `_Tremble` (system_crash) get Speed; `_Hold`
(sleep, hologram) gets neither. LED Bright is on every mood. **Audio** and
**Audio Repeat** are on every mood; **Duration** only on the reaction moods
(excited, alert, surveillance, system_crash). An **`<mood> Reset`** button drops
that mood's stored knobs (`config.forget("tune_<mood>_")`) — an absent key just
means "use the firmware value", so reset is exact and leaves other moods
untouched. `mosquitto_sub -t '<prefix>/tune/#'` shows the retained current
values.

Mood audio is autonomous (`sound.mood_sound_task`, always running, works
offline once a knob is set): it never starts a clip over a still-playing one
(BUSY pin) or over a user-selected sound, and it does **not** touch the HA Sound
entity. `system_crash` no longer screams on its own — pick `scream` in its Audio
dropdown to bring that back.

## Servo — `app/servo.py`

One always-running `servo_task` owns the PWM. Each 20 ms tick it asks the
current mode's behaviour for a setpoint and rate-limits `pos` toward it
(`_approach`: trapezoidal velocity, accel- and speed-limited, snaps on the
final tick so it never overshoots). Because `pos`/`vel` can't jump, a mode
change at any instant is a smooth redirect — no task cancellation. A behaviour's
`target()` returns `(setpoint, max_speed)` or `(setpoint, max_speed,
max_accel)` — the 3rd element lets a mode crack harder than the
`SERVO_MAX_ACCEL` default.

Behaviours (`SERVO_BEHAVIORS[mode]`, fresh instance per switch; they never touch
the servo): `_Hold` (sleep, hologram), `_Sweep` (surveillance — edge-to-edge
oscillation), `_Wander` (standby, awake — long idle, then a slow move to a
random spot), `_Dart` (alert ≈ measured 150°/s darts with 1.5–3.5 s pauses;
excited ≈ frantic 260°/s with 0.5–1.4 s pauses and frequent "double-takes" —
same class, different params), `_Tremble` (system_crash jitter).
`SERVO_MODE_TIMEOUT` is the *firmware default* auto-revert (system_crash → prior
mode after 10 s); the per-mood **Duration** HA knob overrides it (0 = permanent).
A landed-via-auto-revert mode won't itself auto-revert, so it can't ping-pong.
`SERVO_ON_ENTER` (one-shot on mode entry) is now empty — the system_crash scream
moved to the HA `audio` knob. No position persistence — starts at 90° every boot.

## LEDs — `app/leds.py`

`PixelChannel` per-pixel state machine: `off` / `solid` / `blink` / `breathe`
/ `twinkle` / `rainbow`. `LED_REACTIONS[mode]` is four
`(pattern, colour, colour2, period, bright)` tuples for
`[holoprojector, logic display, rear circle, light bar]`. `led_task` renders
at ~25 fps, independent of the servo (both just read `core.state["mode"]`).
Starter patterns — tune on real pixels.

## Sound — `app/sound.py`

`SOUND_FOLDERS` maps a category to `(folder, count)` (counts hard-coded); a
trigger plays a random track in that folder. `busy_monitor_task` watches BUSY
to clear `state["sound"]` when playback ends (with a ~2 s fallback for very
short tracks), so the UI can un-light the button, and publishes the BUSY level
as `sound.is_playing()`.

`mood_sound_task` drives per-mood audio from the HA `audio` / `audio_gap` knobs
(see "Tuning moods from Home Assistant"): on mood entry, and every `audio_gap`
seconds after, it plays a random clip from the mood's chosen category — skipped
if `is_playing()` or a user clip is going. It never sets `state["sound"]`, so
it's invisible to the HA Sound select, and it runs offline.

SD-card layout, how to add clips, and what the DFPlayer serial protocol can and
can't do: **[dfplayer.md](dfplayer.md)**.

## Display — `app/display.py`

Optional SSD1306 128×64 OLED on I2C0 (`GPIO21`/`22`). `app/oled.py` (`machine` +
vendored `lib/ssd1306.py` — no `core` dep, so `provisioning` can use it too)
scans the bus at startup; no panel → `display_task` idles, everything else runs
unchanged. When present it shows device name / current mode / a status line /
volume bar / network line, redrawing on change. The status line shows the
playing sound (`>chat`) or, while the servo is actively moving,
`scanning… / watching… / …` per mode (`servo_task` writes
`core.servo_state["moving"]`). The setup **portal** draws the AP name, password
and URL on the same screen.

## Diagnostics — `app/diag.py`

`snapshot()` → reset cause, uptime, free heap (%), **ESP-IDF internal-RAM free +
low-water** (`idf_free` / `idf_min_free` — a separate pool from the MicroPython
heap; sockets, RMT channels and WiFi buffers come from here), free/total flash,
CPU MHz, RSSI, IP, WiFi SSID + channel, MCU temp, time-synced, task-restart
count, reconnect count, WiFi-association count (`wifi_assoc`). Published to
`<prefix>/diag` every 30 s. Reset cause is a one-shot retained publish — on a
**classic ESP32 a brownout reports as power-on**, so a brownout and a real
power-cycle look identical here; the serial console (`Brownout detector was
triggered`) is the only tell, see `tools/serial-log.py`.

## Updating

**Normal path: USB** — `python3 tools/deploy.py` (see *Getting it onto a
board* above). That's the whole update story for most builds.

### On-device OTA — `app/ota.py`, opt-in

Off unless `core.cfg["ota_url"]` (or `ota_enabled`) is set. `ota.enabled()`
gates the HA Update entity, the `<prefix>/ota/set` subscription, and the boot
auto-check — and OTA needs `network_enabled` anyway.

**Why opt-in:** a classic ESP32 can't complete a TLS handshake to GitHub while
the app is running. mbedTLS needs ~16 KB *contiguous* and MicroPython's GC
doesn't compact, so even with ~65 KB free the allocation fails `ENOMEM`. OTA
therefore pulls **plain HTTP from a LAN mirror** — any static server over the
`droidrefit/` tree (`python3 -m http.server` in the repo root, or drop it in
Home Assistant's `config/www/`). `ota_url` is that base, e.g.
`http://homeassistant.local:8123/local/droidrefit`. The `mip`/GitHub path is
still in the code for PSRAM boards (S2/S3) but untested there.

- **Version**: `app/version.py` `VERSION`. A release = bump it, commit, push,
  refresh the mirror.
- **Manifest**: `droidrefit/package.json` — `check()` reads `version.py`,
  `_http_pull()` downloads each listed path to `<path>.ota` then renames them
  all in once every file has arrived (a mid-download failure leaves the running
  build intact).
- **Backup / rollback**: `update()` copies the managed files to `/bak` and
  writes `/ota.flag`; root `/main.py` counts boots in it and restores `/bak`
  after 3 failures (a crash while `/ota.flag` exists forces a reset so the
  counter advances). `app/main.py` calls `ota.confirm()` once the link is up.
  `boot.py` and root `main.py` are **not** OTA-managed — USB flash only — so
  the bootstrap + rollback are always known-good.
- **Known gap**: a bad build that *hangs* rather than crashes never advances
  the boot counter — recovery there is `noboot.txt` or a USB re-flash.

## Bench tools — `droidrefit/bench/`

`test-boot.py` (servo only) and `test-boot-with-sound.py` (servo + DFPlayer)
— standalone scripts, flash one as `main.py` to smoke-test a bare board.
**Pre-refactor**: they use the old blocking `goto()` motion, not
`app/servo.py`'s driver.

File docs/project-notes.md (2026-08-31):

# CyberBrick R2-D2 + Home Assistant — Project Notes

> **Historical.** The CyberBrick ESP32-C3 core board was retired (its onboard
> regulation browned out under servo + 4 NeoPixels + WiFi). Everything moved
> to a plain ESP32 with an external 5V rail — see the top-level
> [README](../README.md) and [firmware.md](firmware.md). This file is kept for
> *why* the WiFi/MQTT/Home-Assistant scaffolding and the bug fixes below look
> the way they do — that scaffolding carried forward nearly verbatim. The
> CyberBrick-specific parts (`SERVO_REACTIONS`, `LED_REACTIONS`, the `/bbl`
> driver library) did not; `firmware.md` documents what replaced them.

Continuation notes for picking this project up in a new environment (VSCode / Claude Code). This captures the full history: architecture decisions, bugs found and fixed, and current state, so a fresh session has complete context without needing the original chat.

> **2026-08-31 pivot — offline-first.** The droid now boots and runs standalone
> on three front-panel buttons (mode ▲ / mode ▼ / sound); WiFi + Home Assistant
> are an optional layer, off by default (`network_enabled`), reached by holding
> the Sound button ~5 s. The always-on web control panel (`app/webui.py`) was
> **removed** — its `asyncio.start_server` accept loop wedged after WiFi blips
> and leaked sockets from the ESP-IDF internal-RAM pool (`rmt: no mem` flood +
> dead web page). `firmware.md` is authoritative; the MQTT/HA scaffolding
> described below is unchanged and still used when networking is on.

## Goal

Control a CyberBrick-based R2-D2 astromech (stationary display piece) from Home Assistant via MQTT. No physical RC transmitter involved — Home Assistant is the sole controller. Multiple named "reactions" (light + servo behaviors) selectable from an HA dropdown, auto-discovered via MQTT Discovery.

## Architecture

The CyberBrick core board (ESP32-C3, MicroPython) has its stock `boot.py` completely replaced with a custom script that:
- Connects to WiFi + MQTT directly (no RC transmitter/receiver pairing at all)
- Calls the `/bbl` hardware driver library (`leds.py`, `servos.py`) directly, bypassing the stock RC app framework entirely
- Runs a small async task-based reaction dispatcher, driven by MQTT commands from Home Assistant

This is **not** third-party firmware flashing — it's a legitimate MicroPython custom project (CyberBrick's own supported mechanism), just going further than a simple script.

### Why this approach (history)

Two earlier approaches were explored and abandoned:
1. **Emulating transmitter joystick/switch voltages** into an unmodified transmitter shield — would work but requires extra bridge hardware (DAC/PWM circuit) to fake analog signals.
2. **ESP-NOW bridge** (based on rotorman/CyberBrick_ESPNOW) replacing the transmitter, talking to an unmodified receiver — cleaner, but means reimplementing the stock app's LED effects/motor curves from scratch since the community project's receiver code is a bare protocol demo.

Once a fully custom `boot.py` running directly on the receiver (WiFi/MQTT, no transmitter at all) proved to work, both were dropped as unnecessary.

## Hardware facts learned

- **USB power ≠ output power.** The LED/servo output connectors live on a separate "hat" board powered by the battery, not USB. Code can run perfectly over USB with zero errors while nothing physically moves, because the hat board simply isn't powered. **Always verify final LED/servo behavior on battery power**, not USB.
- LED2 (GPIO20) drives a 4-pixel NeoPixel string on the dome. LED1 (GPIO21) is a separate single onboard status LED, not part of the dome.
- Confirmed physical LED pixel mapping (photo-verified): bit 0 = front holoprojector light, bit 1 = logic display (twin squares), bit 2 = rear circle, bit 3 = light bar.
- Dome servo is `servo_idx=1` (GPIO3). Full servo pinout, confirmed via [a Bambu Lab forum post](https://forum.bambulab.com/t/where-is-documentation-on-building-applications-for-cyberbrick/172330/18) that traced it in the `/bbl` `servos.py` source (`servo_idx=1`/GPIO3 matches what this project already verified independently, which is good corroboration for the rest): `servo_idx=2` → GPIO2, `servo_idx=3` → GPIO1, `servo_idx=4` → GPIO0. Channels 2-4 are still unused by this project — the dome is the only servo driven. Leg motors are physically connected but **intentionally not driven** — stationary display piece by design, not a walking robot.
- The physical dome is not perfectly mechanically centered at the software's 90° — worth calibrating/offsetting if precise centering ever matters.

## Real bugs found in CyberBrick's own `/bbl` library (not our code)

- **`servos.py`**: `timing_proc()`'s logic to clear the `step_en` flag on arrival is nested inside a condition that's false exactly when the servo has arrived — so `step_en` never actually clears. `set_angle_stepping()` + polling `step_en` doesn't work as documented. Worked around by driving `set_angle()`/raw PWM directly from our own loop instead.
- **`servos.set_angle()`** uses MicroPython's 10-bit `.duty()` (0-1023) but only spans values 25-127 across the full 0-180° range — ~0.57 duty units per degree, so most single-degree commands don't actually change the physical signal (visible "jumping"/chunkiness). **Fixed by bypassing `set_angle()` and writing `.duty_u16()` (16-bit) directly** to the underlying PWM object: `duty_u16 = int(1638 + angle * 36.3556)`, ~64x finer resolution.
- `reset_info()`'s docstring claims default `radPSec=4`; actual code default is `8.05` — irrelevant once the `set_angle()`/stepping path was abandoned.

## Real bugs found in `umqtt.simple` (third-party MQTT library, not ours)

- `check_msg()` sometimes reports "no message waiting" as `OSError(-1)` instead of returning cleanly — a known library quirk. Swallow specifically that error code, don't treat it as a real failure.
- `connect()` has **no timeout by default** — a bad/unreachable broker hangs forever with zero output. Always call with `timeout=10` and wrap in a retry loop.
- **No reconnect logic of any kind.** Real incident: HA stopped receiving updates from the board (mode/heartbeat/availability all went stale) while the dome kept moving the whole time — the LED/servo tasks don't touch MQTT at all, so that part was actually the architecture working as designed, not a bug. The real cause: `mqtt_task`'s `check_msg()` caught *every* `OSError` unconditionally (not just the harmless `-1` quirk above), so once the underlying socket died — WiFi blip, broker restart, anything — it just kept silently calling `check_msg()` on a dead socket forever, never raising, so `supervise()` never even saw a crash to restart from. `state_publish_task`/`heartbeat_task` held the same now-dead `client` object too, since it was passed in once as a fixed argument at startup. Fixed with: (1) a shared `conn = {"client": ...}` / `link_state = {"down": ...}` pair instead of passing `client` as a fixed arg, so a reconnect is picked up by every task on its next loop iteration automatically; (2) actually re-raising/flagging real errors instead of swallowing them all; (3) a new `connection_watchdog` task that checks WiFi + `link_state` every 15s and runs a full reconnect (fresh `MQTTClient`, re-subscribe, re-publish birth + discovery) when needed. One residual limit: `connect_wifi()`/`connect_mqtt()`/`ntptime.settime()` are still synchronous library calls under the hood, so a reconnect can briefly stall `led_task`/`servo_task` for a couple seconds — far better than the ~60s a fully blocking retry loop would cause, but not zero.

## Software gotchas worth remembering

- **File transfers can silently truncate** with no error at write time — always verify with `os.stat()` size + check the actual tail content matches what's expected after any file transfer of consequence. Arduino Lab's Files-panel drag-and-drop proved more reliable than pasting into the on-device editor for large files.
- **Ctrl-C stops a running async loop; Ctrl-B does not** (it only exits raw-REPL mode). A full power cycle is often needed between test iterations — hardware timers and singleton driver objects can survive a soft reset.
- `LEDController` can only hold **one** effect config at a time, even though it addresses 4 physical pixels — calling `set_led_effect()` twice with different masks overwrites rather than layers. Solved by bypassing it entirely and driving the raw `NeoPixel` object via a custom per-pixel state machine (`PixelChannel` class).
- `urandom.getrandbits(16)` only covers ~65 seconds — silently caps any attempt at multi-minute random intervals. Combine two 16-bit calls for real 32-bit randomness (`rand_ms()` helper).
- `uasyncio.gather()` aborts **all** sibling tasks if any one of them raises an unhandled exception — a bug in one task (e.g. `led_task`) can silently kill unrelated tasks (e.g. `heartbeat_task`). Fixed with a `supervise()` wrapper that catches exceptions per-task and restarts just that task, isolating failures.
- **A directory with no `__init__.py` still imports successfully as an empty "namespace package"** in MicroPython — it doesn't raise. This bit us directly: an initial `config/config.py` layout meant `import config` resolved straight to the empty `config/` directory (found via the root path that `boot.py`/`main.py` already rely on) *before* anything looked inside it for the same-named `config.py` submodule, so `from config import WIFI_SSID` failed with `ImportError: no module named 'config.WIFI_SSID'` — a real device error, not a hypothetical. Fixed by putting the values directly in `config/__init__.py` instead of a separate same-named file inside the package; that's what actually runs when the package itself is imported, so there's nothing left to be shadowed.

## Repo layout

Mirrors the device's root filesystem directly, since that's what gets copied onto the board:

- `boot.py` — trivial bootstrap (`import main`); runs on every power-on
- `main.py` — all actual logic (formerly a single monolithic `boot.py`): WiFi/MQTT, reaction dispatch, LED/servo engines
- `config/__init__.py.example` — checked in, placeholder WiFi/MQTT values
- `config/__init__.py` — gitignored, real credentials; created locally by copying the example file (must be named `__init__.py`, not `config.py` — see "Software gotchas worth remembering" above)
- `umqtt/simple.py` — vendored unmodified from micropython-lib (MIT), not our code

## Current firmware architecture (`main.py`)

- **WiFi**: connects on boot, disables power-save (`wlan.config(pm=wlan.PM_NONE)`) — ESP32's default WiFi power-saving causes intermittent multi-second latency stalls otherwise. ESP32-C3 is 2.4GHz only.
- **MQTT**: `umqtt.simple` (vendored at `/umqtt/simple.py`, not preinstalled), with the timeout/retry fix above. Registers a Last Will and Testament (`r2d2/availability` → `offline`, retained) so Home Assistant can detect an ungraceful disconnect near-instantly, plus a birth message (`online`) on successful connect.
- **Reaction dispatch**: incoming JSON on `r2d2/command` (`{"mode": "..."}`) sets `state["mode"]`; `led_task` and `servo_task` independently read that and apply the matching config from `LED_REACTIONS`/`SERVO_REACTIONS`.
- **LED engine**: custom `PixelChannel` class drives the raw NeoPixel directly, per-pixel independent state machine. Pattern types: `off`, `solid`, `blink`, `breathe` (sine pulse), `twinkle` (random cross-fade between colors, modeled on real R2-D2 logic-display behavior), `rainbow` (smooth HSV hue rotation, optional breathing envelope).
- **Servo engine**: `duty_u16`-based smooth driving. Servo "kinds": `center` (smooth home-to-90), `sweep` (continuous back-and-forth), `jitter` (small random trembling around a fixed point), `random_walk` (bounded random hops across a range), `wander` (slow deliberate glide to a random point + real pause before the next), `standby_cycle` (see below).
- **`standby` mode** is special: a full synced state machine shared between `led_task` and `servo_task` via `standby_state = {"phase": "idle"}` — idle (lights dim/off, still) → active (bright, servo moves) → suspending (dims back down) → repeat every ~3-5 minutes. Every other mode has LED and servo behavior running fully independently; this is the one exception.
- **Debug logging**: runtime-toggleable via an MQTT switch entity (`state["debug"]`, default off), publishes to `r2d2/log` in addition to console when on.
- **Real timestamps**: `sync_time()` calls `ntptime.settime()` once WiFi connects (ESP32-C3 has no battery-backed RTC, so without this the clock is meaningless — `time.ticks_ms()` just counts up from 0 on every power-on). `dbg()`/`heartbeat_task` use a `timestamp()` helper that returns a real `YYYY-MM-DD HH:MM:SSZ` date once synced, falling back to `boot+<ms>` before that (or forever, on a MicroPython build without `ntptime` — guarded with a try/except at import). Added after a debugging session where a stale, unrelated log file (see "Confirm the stock CyberBrick backup files" below) got mistaken for live output purely because nothing had a date on it.
  - **Real-world observed**: `[time] NTP sync failed ... [Errno 116] ETIMEDOUT` on first boot after adding this. `pool.ntp.org` round-robins across many volunteer servers of inconsistent reachability, and `ntptime.settime()` makes exactly one attempt with no retry of its own — a single ETIMEDOUT here doesn't mean NTP is actually blocked on this network. Fixed with two layers: `sync_time()` now retries 3x with a short pause between attempts, and `connection_watchdog` independently keeps calling it every 15s until it succeeds, regardless of WiFi/MQTT health — otherwise a still-unsynced clock would just wait for an unrelated link drop to trigger a retry as a side effect, which could be a very long time on an otherwise-stable connection.
  - **`log_always()`**: `sync_time()`'s retry/success/failure messages, `connect_wifi()`/`connect_mqtt()`'s status lines, and `connection_watchdog`'s unhealthy/reconnected/failed messages all publish to `r2d2/log` unconditionally now, not just to console — `dbg()` is now a thin wrapper around `log_always()` that adds the debug-switch gate back for everything else. Same reasoning as the heartbeat topic being independent of the debug flag: connectivity/reconnect/time-sync lifecycle events are worth seeing in HA without remembering to flip debug on first. Naturally degrades to console-only whenever no MQTT client exists yet to publish through — unavoidable during the WiFi/MQTT handshake itself (first boot, and the start of every reconnect), since that's precisely the moment nothing's connected yet; the watchdog's own "reconnected" line is guaranteed deliverable though, since by then a fresh working client exists.
- **Heartbeat**: publishes to a dedicated `r2d2/heartbeat` topic every 60s, independent of the debug flag — paired with an HA sensor using `expire_after: 180` (3x the interval) for automatic staleness detection. Payload is now a real date via `timestamp()`, not a raw tick count.
- **MQTT Discovery**: four auto-created HA entities — mode select, debug switch, heartbeat sensor — no manual YAML config needed. Discovery payloads are retained (persist across HA restarts even if the board is offline).
- **Task isolation**: every task runs through a `supervise()` wrapper so one task crashing can't take down its siblings via `uasyncio.gather()`.
- **Connection recovery**: `connection_watchdog` task detects a dropped WiFi/MQTT link and performs a full reconnect — see the `umqtt.simple` "No reconnect logic" entry above for why this exists.

## Current reactions (9 total, alphabetically sorted in the HA dropdown)

| Mode | Lights | Servo |
|---|---|---|
| `standby` | Synced cycle: dim/off → bright → dim (see above) | Synced with lights |
| `awake` | Rainbow front holo + twinkle logic display (test mode, same look as old standby) | Continuous slow "wander" — random glide + pause every 2-5 min |
| `excited` | Fast orange blink everywhere | Fast sweep, full 1-179° range |
| `surveillance` | Solid white front + twinkling logic display + breathing rear | Slow sweep |
| `alert` | All-red blink/twinkle | Fast sweep |
| `sleep` | Everything off except very slow/dim logic-display twinkle | Centered/still |
| `system_crash` | Chaotic multi-color twinkle/strobe | Snap to 145° then tight jitter |
| `system_crash_extreme` | Same lights as system_crash | Wide random walk instead of jitter |
| `hologram` | All 4 zones blink red in sync (700ms) — "on a call" indicator | Centered/still |

## Open / next steps

1. **Sound module**: decided on a DFPlayer Mini (UART-controlled MP3 player, real files off microSD, genuinely indexed via `play(track_id)`) for real movie-accurate R2-D2 sound clips. An earlier candidate (micha833/BuildaDroid_sound_generator, an Arduino Nano + PWM-triggered tone synthesizer) was evaluated and rejected — it only produces procedural generative chatter, not selectable real audio files. Still waiting on hardware + sound files to be sourced (movie-accurate clips should come from the astromech.net / R2 Builders Club community, not generated — that's copyrighted film audio). Planned integration: separate `r2d2/sound` MQTT topic (independent from `r2d2/command` so it doesn't disturb the active LED/servo mode) + a second HA select entity.
2. Physical dome mechanical centering — not yet calibrated.
3. Confirm the stock CyberBrick backup files (original `boot.py`, `/app`, `/bbl`, `/rc_config`) are stored somewhere durable off the board. `logging.0.log` at the repo root is very likely part of that original backup — its content (`[MAIN]SLAVE_IDX`, `[CTRL]ANALOG_CH`, `EFFECT:`, `PWRON_RESET`) is the *stock RC app's* own log format, not this project's — `main.py`/`boot.py` never write to a file at all, only to console + `r2d2/log` over MQTT. It got mistaken for live output during a debugging session purely because it has no dates on it (see "Real timestamps" above — this is exactly the problem that motivated adding those). **Still undecided**: keep it as a labeled stock-firmware backup artifact, or remove it now that it's more likely to cause confusion than help.
4. **`.mpy` precompilation** — deferred, not needed right now. Findings from researching it, so this doesn't need to be re-derived later:
   - MicroPython supports `boot.mpy`/`main.mpy` as direct drop-in replacements for `boot.py`/`main.py` at the filesystem root (confirmed in MicroPython's own docs) — our current `boot.py`/`main.py` split needs no restructuring to adopt this later.
   - Anything reached via a normal `import` is compilable the same way — so `main.py`, `config/__init__.py`, and `umqtt/simple.py` all qualify too.
   - If both a `.py` and `.mpy` of the same module exist on the device, the `.py` source wins — you'd upload only the `.mpy`, not both, to actually get the benefit.
   - **Real risk, why this is deferred**: `.mpy` bytecode is version-locked to the MicroPython build that compiled it — a mismatch fails at import time (`incompatible .mpy file`), which would break `main.py` from ever starting since CyberBrick ships a customized MicroPython fork. Compiling requires first checking the on-device version via REPL (`import sys; print(sys.implementation)`) and using a matching `mpy-cross` (available pinned per-release on PyPI, e.g. `pip install mpy-cross==1.24.1`; versions 1.12–1.28.0 confirmed available as of this writing).
   - **Confirmed target values (checked directly on the board)**: MPY version format `6`, sub-version `3` — i.e. mpy version "6.3". Per MicroPython's own compatibility table, version 6.3 corresponds to MicroPython **1.23.0 and later** (until whichever later release next bumps the mpy version — not yet checked). That narrows the candidate `mpy-cross` builds to try first (e.g. `pip install mpy-cross==1.23.0`), but since CyberBrick's firmware is a customized fork, still treat this as a strong starting point to test, not a guaranteed exact match — verify by actually compiling and importing a small test module on the board before trusting it for real files.
   - If revisited: keep `.py` files as the tracked-in-git source of truth, treat `.mpy` as a generated build artifact (e.g. a small script/Makefile producing a gitignored `build/` output), not something hand-maintained.

## Useful references

- Official CyberBrick receiver source + `/bbl` library: github.com/CyberBrick-Official/CyberBrick_Controller_Core
- CyberBrick MicroPython custom project docs: wiki.bambulab.com/en/makerworld/cyberbrick/ai-advanced-programming
- `umqtt.simple` source: github.com/micropython/micropython-lib/tree/master/micropython/umqtt.simple — vendored unmodified in this repo at `umqtt/simple.py`
- Full narrative writeup/tutorial (published): this repo's guide file

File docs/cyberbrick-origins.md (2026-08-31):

# Controlling a CyberBrick Astromech Droid from Home Assistant

> **Historical.** This documents the project's first chapter: replacing the
> firmware on a **CyberBrick ESP32-C3 core board**. That board was retired
> because its onboard regulation couldn't feed servo + 4 NeoPixels + WiFi
> without browning out. The project now runs on a plain ESP32 with a proper
> external supply and a from-scratch modular firmware — see the top-level
> [README](../README.md) and [docs/firmware.md](firmware.md). This writeup is
> kept for the reverse-engineering notes (the `/bbl` driver library, the LED
> engine, the MQTT/HA-discovery approach), most of which carried forward.

---

This is a writeup of how I replaced the stock CyberBrick RC firmware on an astromech droid build with custom MicroPython that connects directly to Home Assistant over WiFi/MQTT — no physical remote control involved. The droid runs nine distinct "reactions" (`standby`, `awake`, `excited`, `surveillance`, `alert`, `sleep`, `system_crash`, `system_crash_extreme`, `hologram`), each with independently animated dome lights and a servo behavior, all switchable from a Home Assistant dashboard.

If you've got a [CyberBrick](https://makerworld.com/en/cyberbrick) core board driving some kind of prop or droid and want smart-home control instead of (or in addition to) the RF remote, this should get you most of the way there.

## Background: what CyberBrick is

CyberBrick is a hobbyist RC platform from MakerWorld/Bambu Lab — a small ESP32-C3-based "core" board that runs MicroPython, paired with interchangeable "shields" (a transmitter shield with joysticks/switches, and a receiver shield with servo/motor/LED outputs). The stock setup: you build a config in CyberBrick's app (mapping joystick/switch channels to LEDs, servos, motors), upload it to the receiver, and drive it with a paired physical transmitter over a proprietary 2.4GHz link.

That's a great system if you want an RC vehicle. It's the wrong shape if you want a stationary display piece that reacts to commands from your smart home setup instead of a joystick.

## The approach

The core insight: the CyberBrick core board is just an ESP32-C3 running plain MicroPython, and it has full, ordinary WiFi and network stack access. The stock RC application (`rc_main.py` → `rc_module` → `BBL_Controller`) is just *one* MicroPython program that happens to run at boot — nothing stops you replacing `boot.py` entirely with your own script that talks to WiFi/MQTT instead of a paired transmitter, while still calling the same low-level hardware driver library (`/bbl` — LEDs, servos, motors, buzzer) that the stock app uses.

This is **not** third-party firmware flashing (which CyberBrick explicitly warns against and which can brick the board) — it's using the officially-supported MicroPython custom-project mechanism, just going further than a simple script.

Architecture:

```
Home Assistant  →  MQTT (Mosquitto)  →  CyberBrick core (custom boot.py/main.py)  →  /bbl drivers  →  LEDs + servo
```

No transmitter, no receiver pairing, no bridge hardware. The board joins your WiFi, subscribes to an MQTT command topic, and drives the hardware directly.

## Project structure

This repo mirrors the device's own root filesystem — copy it straight onto the board's storage as-is:

```
boot.py                   # trivial bootstrap: import main
main.py                   # everything else — WiFi/MQTT, reaction dispatch, LED/servo engines
config/
    __init__.py.example    # checked in — placeholder WiFi/MQTT values
    __init__.py            # gitignored — your real credentials, not tracked
umqtt/
    simple.py             # vendored from micropython-lib (see Acknowledgments)
```

Before flashing, set up your own credentials:

```sh
cp config/__init__.py.example config/__init__.py
# then edit config/__init__.py with your real WiFi SSID/password and MQTT broker/user/password
```

`config/__init__.py` is gitignored on purpose — it never gets committed, so your credentials don't end up in git history or on a public remote. `main.py` pulls them in with `from config import (WIFI_SSID, WIFI_PASSWORD, ...)`.

It has to be `__init__.py`, not e.g. `config.py` inside that folder. MicroPython treats any directory with no `__init__.py` as a valid (empty) "namespace package" — so `import config` would resolve straight to the empty `config/` directory *before* ever looking inside it for a same-named submodule, and `from config import WIFI_SSID` would fail with `ImportError: no module named 'config.WIFI_SSID'`. Putting the values directly in `__init__.py` sidesteps that: it's what actually runs when the package itself is imported, so there's no separate submodule left to be shadowed.

## What I initially considered (and abandoned)

Worth documenting the false starts, since they're informative:

1. **Emulating the transmitter's joystick/switch signals electrically.** The X12 transmitter shield's inputs are simple analog voltages (joysticks, ~0–2.5V range on a 12-bit ADC) and digital grounds (buttons/switches) — in theory you could wire a second microcontroller to fake these signals into an *unmodified* transmitter, which would then talk to an unmodified receiver exactly as if a human were operating it. This is real and would work, but it means building a whole second piece of hardware (a DAC or PWM+filter circuit) just to reimplement something we could do far more directly.

2. **Replacing the transmitter with an ESP-NOW bridge.** CyberBrick's receiver-to-transmitter link uses ESP-NOW (a WiFi-adjacent protocol), and a community project ([rotorman/CyberBrick_ESPNOW](https://github.com/rotorman/CyberBrick_ESPNOW)) has reverse-engineered this protocol to let an RC radio control an unmodified CyberBrick receiver directly. This is a legitimately good approach if you want to keep the receiver's official app/config running unmodified — but it meant reimplementing the stock app's LED effects and motor curves in a from-scratch receiver-side script, since the community project's receiver code is a bare protocol demo, not the full stock feature set.

Once I actually got a REPL connection to the board and found the receiver could run a **fully custom `boot.py`** with direct WiFi/MQTT access, both of the above became unnecessary — there's no need to fake a transmitter at all when the receiver itself can just talk to Home Assistant.

## Step 1: Get a REPL connection to the board

You need physical/USB access to the CyberBrick core board once, to replace `boot.py`.

1. Plug the core board into your computer via USB-C
2. Find the serial port:
   - **macOS**: `ls /dev/tty.*` — look for something like `/dev/tty.usbmodem21101`
   - **Windows**: Device Manager → Ports (COM & LPT)
   - **Linux**: `ls /dev/ttyACM*`
3. Install [Arduino Lab for MicroPython](https://labs.arduino.cc/en/labs/micropython) (free) — gives you both a REPL console and a file browser in one tool
4. Connect to the port you found. You should land at a `>>>` prompt.

**Back up the stock files first**, using Arduino Lab's Files panel (not the REPL) — this is your restore point:
- `boot.py`
- everything under `/app`
- everything under `/bbl`
- `/rc_config`

### A few REPL gotchas worth knowing up front

- **Large pastes into the raw REPL can silently truncate.** Twice during this project, a multi-thousand-character file transfer via the on-device text editor ended up cut off mid-file, with *no error at write time* — only discovered later via `os.stat()` and checking the actual tail of the file against what it should end with. **Use Arduino Lab's Files panel (drag/drop a file from your computer) rather than pasting into the on-device editor** for anything of real size — it's far more reliable.
- **Ctrl-C stops a running loop. Ctrl-B does not** — it only exits "raw REPL" mode back to the interactive prompt; a running async loop keeps going in the background underneath you, causing confusing mixed output from old and new test runs.
- **A soft reset (Ctrl-D) doesn't always fully reset hardware state.** Timers and singleton driver objects can survive a Ctrl-D. When in doubt, do a full power cycle (unplug everything, plug back in) between test iterations.
- If pasting multi-line code directly at the `>>>` prompt gives you `IndentationError`, the REPL's own auto-indent is colliding with your pasted indentation. Use **Ctrl-E** (paste mode), paste, then **Ctrl-D** to run it as-is.

## Step 2: Understand the hardware driver library

Before writing anything, it's worth reading the actual source of the driver modules you'll be calling — CyberBrick's docs don't cover everything, and there are real bugs worth knowing about upfront.

### LEDs (`/bbl/leds.py`)

```python
from leds import LEDController
led2 = LEDController("LED2")   # singleton per channel; LED2 = GPIO20, LED1 = GPIO21
led2.set_led_effect(mod, duration_ms, repeat_count, led_index, rgb)
```

- `mod`: `0` = solid, `1` = blink, `2` = **breathing** (a sine-wave pulse — not exposed anywhere in CyberBrick's own config UI, only usable by calling this directly)
- `led_index`: a 4-bit mask, one bit per physical NeoPixel on that output (`0b1111` = all four)
- **Important limitation**: `LEDController` only holds **one** effect configuration at a time, even though it addresses 4 physical pixels. Calling `set_led_effect()` twice with two different masks doesn't layer — the second call just overwrites the first. If you want different pixels doing genuinely different things simultaneously (which you probably do), you need to bypass `LEDController` and drive the raw `NeoPixel` object yourself (see Step 4).
- `set_led_effect()` only configures the target state — nothing animates until you call `led2.timing_proc()` repeatedly (every ~10ms) in a loop.

### Servos (`/bbl/servos.py`)

```python
from servos import ServosController
servos = ServosController()   # one instance controls all 4 channels
servos.set_angle(servo_idx, angle)                     # immediate jump, 0-180°
servos.set_angle_stepping(servo_idx, angle, step_speed) # gradual move
```

- **Real bug found in this file**: `timing_proc()`'s logic to clear the internal `step_en` flag back to `False` on arrival is nested inside a conditional that becomes false exactly when the servo *has* arrived — so `step_en` never actually clears, and polling it to detect "movement finished" doesn't work as the docstring implies.
- **Second bug**: `set_angle()` uses MicroPython's 10-bit `.duty()` (0-1023), but only spans values 25-127 across the full 0-180° range — about 0.57 duty units per degree, so most single-degree commands don't actually change the physical signal (visible "jumping"/chunkiness).
- **Workaround used**: skip `set_angle()`/`set_angle_stepping()`/`timing_proc()` entirely. Drive the underlying PWM object directly with the 16-bit `.duty_u16()` call instead — about 64x finer resolution:
  ```python
  def angle_to_duty_u16(angle):
      return int(1638 + angle * 36.3556)

  servo_pwm = servos.servos_map[SERVO_IDX - 1]
  servo_pwm.duty_u16(angle_to_duty_u16(angle))
  ```
  Continuous motion (sweeps, wandering, jitter) is then just your own loop calling this repeatedly with your own step size and delay — simpler and fully predictable.
- Also: the docstring for `reset_info()` claims a default rotation speed of 4 rad/sec; the actual code default is `8.05` — irrelevant once you're on the `duty_u16()` path above.

### Buzzer (`/bbl/buzzer.py`)

There's a full RTTTL ringtone-format player (`MusicController`) in here, not just a simple tone generator — genuinely capable of short "chirp" style sequences if you have a piezo speaker wired up. **Watch for a pin conflict**: `BUZZER2` shares GPIO20 with `LED2` — if you're using the dome LED output, only `BUZZER1` (GPIO21) is free.

## Step 3: Confirm your physical LED layout

If your build has multiple addressable LEDs behind one output (like a 4-pixel dome ring), don't guess which bit of `led_index` maps to which physical position — check empirically:

```python
import sys
sys.path.append('/bbl')
from leds import LEDController

led2 = LEDController("LED2")

def show_only(bit_index):
    mask = 1 << bit_index
    led2.set_led_effect(0, 0, 255, mask, 0xFFFFFF)
    led2.timing_proc()

show_only(0)  # then 1, 2, 3 — note what physically lights up each time
```

On my build this mapped to: bit 0 = front holoprojector light, bit 1 = logic-display twin squares, bit 2 = rear circle, bit 3 = light bar.

## Step 4: The multi-zone LED animation engine

Since `LEDController` can't run independent effects per pixel, here's a small standalone engine that drives the raw `NeoPixel` object with per-pixel state. Pattern types in the shipped `main.py`: `off`, `solid`, `blink`, `breathe` (sine pulse), `twinkle` (a randomized color cross-fade, modeled on how real R2-D2 replica "logic displays" behave — they fade between key colors and pause for a random hold at each, rather than blinking on a fixed clock), and `rainbow` (smooth HSV hue rotation with an optional breathing envelope). The core of it:

```python
import sys
sys.path.append('/bbl')
from machine import Pin
from leds import NeoPixel
import time, math, urandom

pin = Pin(20, Pin.OUT)  # your LED output's GPIO
np = NeoPixel(pin, 4, timing=0)

class PixelChannel:
    def __init__(self):
        self.pattern = 'off'
        self.params = {}
        self._from = (0, 0, 0)
        self._to = (0, 0, 0)
        self._start = 0
        self._dur = 1
        self._hold_until = None

    def set(self, pattern, **params):
        self.pattern = pattern
        self.params = params
        if pattern == 'twinkle':
            self._hold_until = None
            self._pick_target(time.ticks_ms())

    def _pick_target(self, now):
        colors = self.params.get('colors', [(0, 40, 90), (255, 255, 255)])
        self._from = self._to
        self._to = colors[urandom.getrandbits(8) % len(colors)]
        self._start = now
        self._dur = self.params.get('fade_ms', 500)

    def color(self, now):
        p, params = self.pattern, self.params
        if p == 'off':
            return (0, 0, 0)
        if p == 'solid':
            return params.get('rgb', (255, 255, 255))
        if p == 'blink':
            period = params.get('period_ms', 500)
            on = (now % period) < (period // 2)
            return params.get('rgb', (255, 255, 255)) if on else (0, 0, 0)
        if p == 'breathe':
            period = params.get('period_ms', 1500)
            phase = (now % period) / period
            b = (1 + math.sin(2 * math.pi * phase - math.pi / 2)) / 2
            r, g, bl = params.get('rgb', (255, 255, 255))
            return (int(r * b), int(g * b), int(bl * b))
        if p == 'twinkle':
            if self._hold_until is not None and now >= self._hold_until:
                self._pick_target(now)
            elapsed = time.ticks_diff(now, self._start)
            if elapsed >= self._dur:
                if self._hold_until is None:
                    hold_max = params.get('hold_ms', 400)
                    self._hold_until = now + (urandom.getrandbits(8) % hold_max) + 50
                return self._to
            frac = elapsed / self._dur
            f, t = self._from, self._to
            return (int(f[0]+(t[0]-f[0])*frac), int(f[1]+(t[1]-f[1])*frac), int(f[2]+(t[2]-f[2])*frac))
        return (0, 0, 0)

channels = [PixelChannel() for _ in range(4)]

def apply_led_reaction(cfg):
    for idx, (pattern, params) in cfg.items():
        channels[idx].set(pattern, **params)

def led_tick():
    now = time.ticks_ms()
    for i, ch in enumerate(channels):
        np[i] = ch.color(now)
    np.write()
```

*(the `rainbow` pattern and its HSV helper are a bit more code — see `main.py` for the complete, current version)*

A "reaction" is then just a dict mapping pixel index → `(pattern, params)`:

```python
FRONT_HOLO, LOGIC_DISPLAY, REAR_CIRCLE, LIGHT_BAR = 0, 1, 2, 3
BLUE, WHITE, ORANGE, RED = (0,40,90), (255,255,255), (255,110,0), (255,0,0)

LED_REACTIONS = {
    "alert": {
        FRONT_HOLO:    ('blink', {'rgb': RED, 'period_ms': 200}),
        LOGIC_DISPLAY: ('twinkle', {'colors': [RED, WHITE], 'fade_ms': 100, 'hold_ms': 80}),
        REAR_CIRCLE:   ('blink', {'rgb': RED, 'period_ms': 200}),
        LIGHT_BAR:     ('blink', {'rgb': RED, 'period_ms': 100}),
    },
    # ...more reactions — see the "Current reactions" table below and main.py
}
```

## Step 5: WiFi + MQTT

The core board's `network` module is ordinary MicroPython WiFi:

```python
import network, time

def connect_wifi(ssid, password):
    wlan = network.WLAN(network.STA_IF)
    wlan.active(True)
    if not wlan.isconnected():
        wlan.connect(ssid, password)
        for _ in range(30):
            if wlan.isconnected():
                break
            time.sleep(1)
    try:
        wlan.config(pm=wlan.PM_NONE)  # disable WiFi power-save — see note below
    except Exception as e:
        print("could not disable power save:", e)
    print("connected:", wlan.isconnected(), wlan.ifconfig())
```

**One important gotcha**: ESP32 chips enable WiFi power-saving by default once connected, which periodically cycles the radio off between beacon intervals. This can introduce intermittent multi-second (sometimes tens-of-seconds) latency spikes that look like random "stalls" — `wlan.config(pm=wlan.PM_NONE)` disables it. Note this constant isn't available on every MicroPython build; wrap it in a try/except.

**ESP32-C3 is 2.4GHz only.** If your network has separate 2.4/5GHz SSIDs, make sure you're connecting to the 2.4GHz one.

For MQTT, there's no built-in client — this repo vendors [`umqtt.simple`](https://github.com/micropython/micropython-lib/blob/master/micropython/umqtt.simple/umqtt/simple.py) at `umqtt/simple.py` (see [Acknowledgments](#acknowledgments)), which you copy to the board at `/umqtt/simple.py` along with everything else.

Two real bugs worth patching around:

```python
async def mqtt_task():
    while True:
        client = conn["client"]  # see "Reconnecting" below for why this
        if client is not None:   # isn't just a fixed argument
            try:
                client.check_msg()
            except OSError as e:
                # umqtt.simple has a known issue where "no message waiting"
                # is sometimes reported as OSError(-1) instead of returning
                # cleanly — swallow specifically that case. Anything else
                # is a real link failure, and must NOT be swallowed too —
                # see "Reconnecting" below for why that matters.
                if e.args and e.args[0] == -1:
                    pass
                else:
                    print("mqtt error:", e)
                    link_state["down"] = True
        await uasyncio.sleep_ms(100)
```

```python
async def connect_mqtt():
    from umqtt.simple import MQTTClient
    client = MQTTClient(MQTT_CLIENT_ID, MQTT_BROKER, port=1883, user=MQTT_USER, password=MQTT_PASSWORD)
    # umqtt.simple's connect() has NO timeout by default — a bad/unreachable
    # broker can hang FOREVER with zero output. Always pass an explicit one.
    for attempt in range(5):
        try:
            client.connect(timeout=10)
            return client
        except Exception as e:
            print("mqtt connect attempt", attempt, "failed:", e)
            await uasyncio.sleep_ms(2000)
    raise RuntimeError("could not connect to MQTT")
```

Credentials for both of these come from `config/__init__.py` (see [Project structure](#project-structure)) rather than being hardcoded — `main.py` does `from config import (WIFI_SSID, WIFI_PASSWORD, MQTT_BROKER, MQTT_PORT, MQTT_USER, MQTT_PASSWORD, MQTT_CLIENT_ID)`.

The shipped `main.py` also registers a **Last Will and Testament** on connect (`client.set_last_will(...)`) — the broker auto-publishes `r2d2/availability` → `offline` (retained) if the board ever drops off ungracefully (WiFi loss, power loss, crash), paired with a birth message (`online`) once connected. That's what backs the HA availability/heartbeat entities in Step 6.

### Reconnecting

`umqtt.simple` has no reconnect logic of its own, and it's easy to accidentally paper over that: an early version of `mqtt_task` here caught *every* `OSError` from `check_msg()`, not just the harmless `-1` quirk above. Once the underlying socket died — a WiFi blip, a broker restart, anything — it just kept silently calling `check_msg()` on a dead socket forever, never raising, so nothing ever noticed or recovered. In practice this looked like the board falling silent in Home Assistant while everything else (LEDs, servo) kept running fine, since those don't touch MQTT at all.

The fix has two parts. First, `client` is a shared mutable reference (`conn = {"client": ...}`) instead of a fixed argument to each task — a reconnect creates a *new* `MQTTClient`, and every task needs to pick that up on its next loop iteration rather than keep talking to the one it originally started with. Second, a `connection_watchdog` task checks WiFi + a `link_state["down"]` flag (set by any task that hits a real failure) every 15s, and runs a full reconnect — fresh client, re-subscribe, re-publish birth message and discovery — when needed. `connect_wifi()` and `connect_mqtt()` are both `async def` with `await uasyncio.sleep_ms(...)` in their retry loops rather than blocking `time.sleep()`, specifically so a reconnect attempt doesn't freeze the LED/servo animations while it runs — a real risk once reconnecting can happen at any time from a background task, not just once at boot.

One residual limit: the individual connect calls themselves (`wlan.connect()`, `client.connect()`, `ntptime.settime()` below) are still synchronous library calls under the hood, so a reconnect can briefly stall animations for a couple of seconds — far better than the ~60s a fully blocking retry loop would cause, but not zero.

`connection_watchdog`'s status lines (link unhealthy, reconnected, reconnect failed) — along with `connect_wifi()`/`connect_mqtt()`'s own — all publish to `r2d2/log` unconditionally via `log_always()` (see "Real timestamps" below), not gated behind the debug switch, so a reconnect happening is actually visible in Home Assistant. The one unavoidable gap: during the handshake itself there's usually no MQTT client yet to publish through (first boot, and the start of every reconnect), so those specific lines land console-only in practice — the "reconnected" confirmation line is the one guaranteed to make it through, since a working client exists by the time it fires.

### Real timestamps

ESP32-C3 has no battery-backed RTC, so `time.ticks_ms()` — used for all the animation timing elsewhere in this project — just counts milliseconds since the last power-on and resets to 0 every boot. That's fine for animation math, but useless for knowing *when* something happened, which matters once you're pulling logs or heartbeat values off the device later. `main.py` calls `ntptime.settime()` once WiFi connects, and a small `timestamp()` helper returns a real date once that's synced (falling back to `boot+<ms>` before that, or forever on a MicroPython build without `ntptime` — guarded with a try/except at import). `dbg()` and the heartbeat payload both use it.

`ntptime.settime()` makes exactly one attempt with no retry, and `pool.ntp.org` round-robins across many volunteer servers of inconsistent reachability — a single `ETIMEDOUT` doesn't mean NTP is actually blocked. `sync_time()` retries 3x, and `connection_watchdog` (see "Reconnecting" above) keeps retrying it independently every 15s until it succeeds. Its retry/success/failure messages publish to `r2d2/log` unconditionally via a `log_always()` helper, not gated behind the debug switch — `dbg()` is just a thin wrapper adding that gate back for everything else — same reasoning as the heartbeat topic itself being independent of the debug flag: connectivity/time-sync lifecycle events are worth seeing in HA without remembering to flip debug on first.

## Step 6: Home Assistant MQTT Discovery

Rather than hand-configuring entities in `configuration.yaml`, the board announces itself to Home Assistant automatically via [MQTT Discovery](https://www.home-assistant.io/integrations/mqtt/#mqtt-discovery) — publish a small JSON payload to a well-known topic, and HA creates the entity on the spot. The shipped firmware publishes three entities this way: a mode **select** (the reaction dropdown), a debug-logging **switch**, and a heartbeat **sensor**.

```python
import ujson

def publish_discovery(client, modes):
    device_info = {
        "identifiers": ["r2d2"],
        "name": "R2D2 Astromech",
        "manufacturer": "CyberBrick (custom firmware)",
    }
    mode_payload = {
        "name": "R2D2 Mode",
        "unique_id": "r2d2_mode_select",
        "options": sorted(modes),
        "state_topic": "r2d2/mode/state",
        "command_topic": "r2d2/command",
        "command_template": '{"mode": "{{ value }}"}',
        "availability_topic": "r2d2/availability",
        "device": device_info,
    }
    client.publish(b"homeassistant/select/r2d2/mode/config",
                    ujson.dumps(mode_payload).encode(), retain=True)
```

*(the debug switch and heartbeat sensor discovery payloads follow the same shape — see `publish_discovery()` in `main.py` for the complete version)*

This gets you a dropdown entity in Home Assistant with your reaction names as options, plus the switch/sensor, with zero manual YAML. Discovery payloads are retained on the broker, so the entities persist across HA restarts even if the board is offline.

A nice bonus: since debug logging goes over MQTT too (`client.publish(b'r2d2/log', line)`, gated by the debug switch), you can watch live debug output from anywhere via HA's MQTT integration → **Listen to a topic** → `r2d2/log`, no serial cable required once it's deployed. The heartbeat sensor (`r2d2/heartbeat`, published every 60s, `expire_after: 180`) gives HA automatic staleness detection independent of debug logging.

## Step 7: Tie it together

The full reaction dispatch loop, split across two files — `boot.py` (trivial, runs on every power-on) and `main.py` (everything else):

```python
# boot.py
import main
```

```python
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

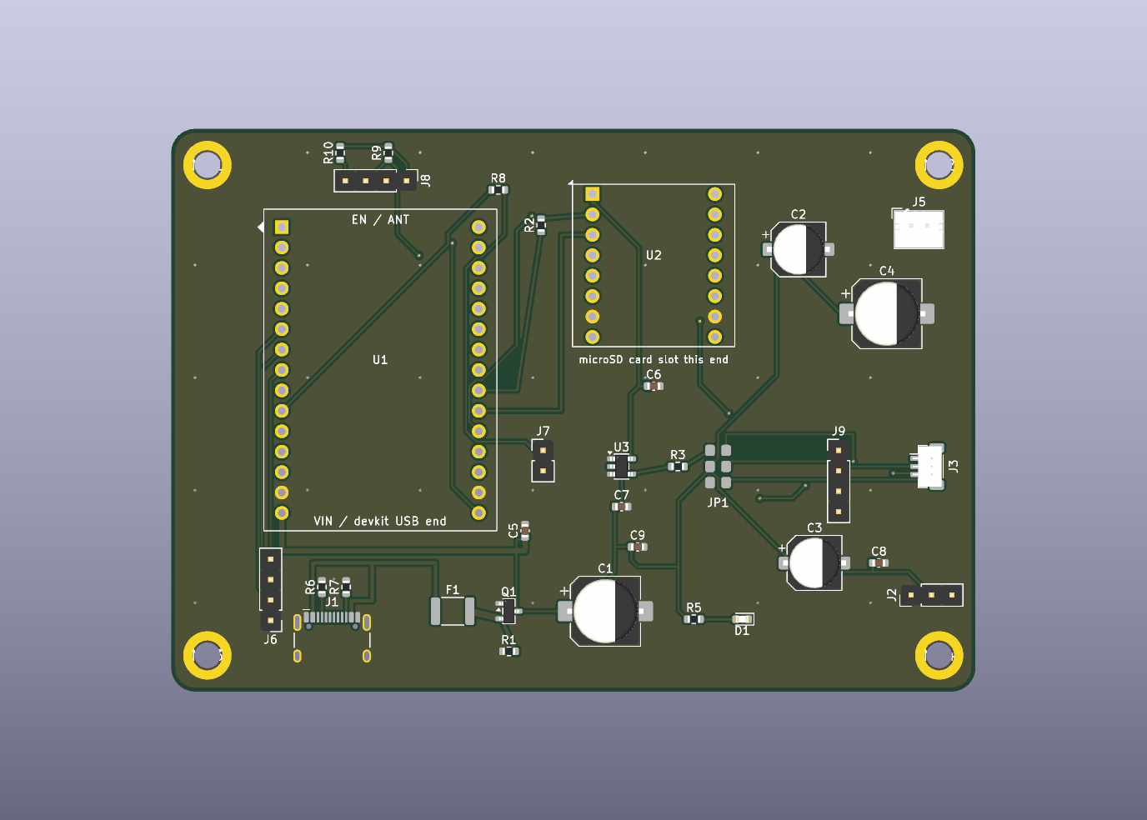
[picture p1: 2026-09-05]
hardware/droidrefit-pcb/fab/droidrefit-pcb-2d-top.png

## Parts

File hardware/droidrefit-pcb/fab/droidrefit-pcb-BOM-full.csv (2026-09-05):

Designator | Value | Qty | Footprint | LCSC | MPN | DNP
C1,C4 | 1000u/10V | 2 | Capacitor_SMD:CP_Elec_8x10.5 | C310838 | RVE1A102M0810 | hand-solder
C2,C3 | 470u/10V | 2 | Capacitor_SMD:CP_Elec_6.3x7.7 | C335982 | RVT1A471M0607 | hand-solder
C5,C6,C7,C8,C9 | 100n | 5 | Capacitor_SMD:C_0603_1608Metric | C14663 | CC0603KRX7R9BB104
D1 | GRN | 1 | LED_SMD:LED_0603_1608Metric | C965804 | XL-1608UGC-04
F1 | PTC 2A hold / 4A trip | 1 | Fuse:Fuse_1812_4532Metric | C18198342 | 1812L200/30GR
J1 | USB-C 5V in | 1 | Connector_USB:USB_C_Receptacle_HCTL_HC-TYPE-C-16P-01A | C2765186 | TYPE-C-16PIN-2MD(073)
J2 | SERVO SIG/+5V/GND | 1 | Connector_PinHeader_2.54mm:PinHeader_1x03_P2.54mm_Vertical | C49257 | 1x3 2.54mm header | hand-solder
J3 | NEOPIXEL JST-SH | 1 | Connector_JST:JST_SH_BM03B-SRSS-TB_1x03-1MP_P1.00mm_Vertical | C160389 | BM03B-SRSS-TB(LF)(SN)
J5 | SPEAKER 4-8ohm | 1 | Connector_JST:JST_PH_B2B-PH-K_1x02_P2.00mm_Vertical | C131337 | B2B-PH-K-S | hand-solder
J6 | BUTTONS | 1 | Connector_PinHeader_2.54mm:PinHeader_1x04_P2.54mm_Vertical |  |  | hand-solder
J7 | BUZZER | 1 | Connector_PinHeader_2.54mm:PinHeader_1x02_P2.54mm_Vertical |  |  | hand-solder
J8 | OLED I2C | 1 | Connector_PinHeader_2.54mm:PinHeader_1x04_P2.54mm_Vertical |  |  | hand-solder
J9 | UART0 ACCESS | 1 | Connector_PinHeader_2.54mm:PinHeader_1x04_P2.54mm_Vertical |  |  | hand-solder
Q1 | AO3401A | 1 | Package_TO_SOT_SMD:SOT-23 | C15127 | AO3401A
R1 | 100k | 1 | Resistor_SMD:R_0603_1608Metric | C25803 | 0603WAF1003T5E
R2 | 1k | 1 | Resistor_SMD:R_0603_1608Metric | C21190 | 0603WAF1001T5E
R3 | 330 | 1 | Resistor_SMD:R_0603_1608Metric | C23138 | 0603WAF3300T5E
R5 | 2k | 1 | Resistor_SMD:R_0603_1608Metric | C22975 | 0603WAF2001T5E
R6,R7 | 5.1k | 2 | Resistor_SMD:R_0603_1608Metric | C23186 | 0603WAF5101T5E
R8 | 100 | 1 | Resistor_SMD:R_0603_1608Metric | C22775 | 0603WAF1000T5E
R9,R10 | 4.7k | 2 | Resistor_SMD:R_0603_1608Metric | C23162 | 0603WAF4701T5E
U3 | 74AHCT1G125 | 1 | Package_TO_SOT_SMD:SOT-23-5 | C7484 | SN74AHCT1G125DBVR

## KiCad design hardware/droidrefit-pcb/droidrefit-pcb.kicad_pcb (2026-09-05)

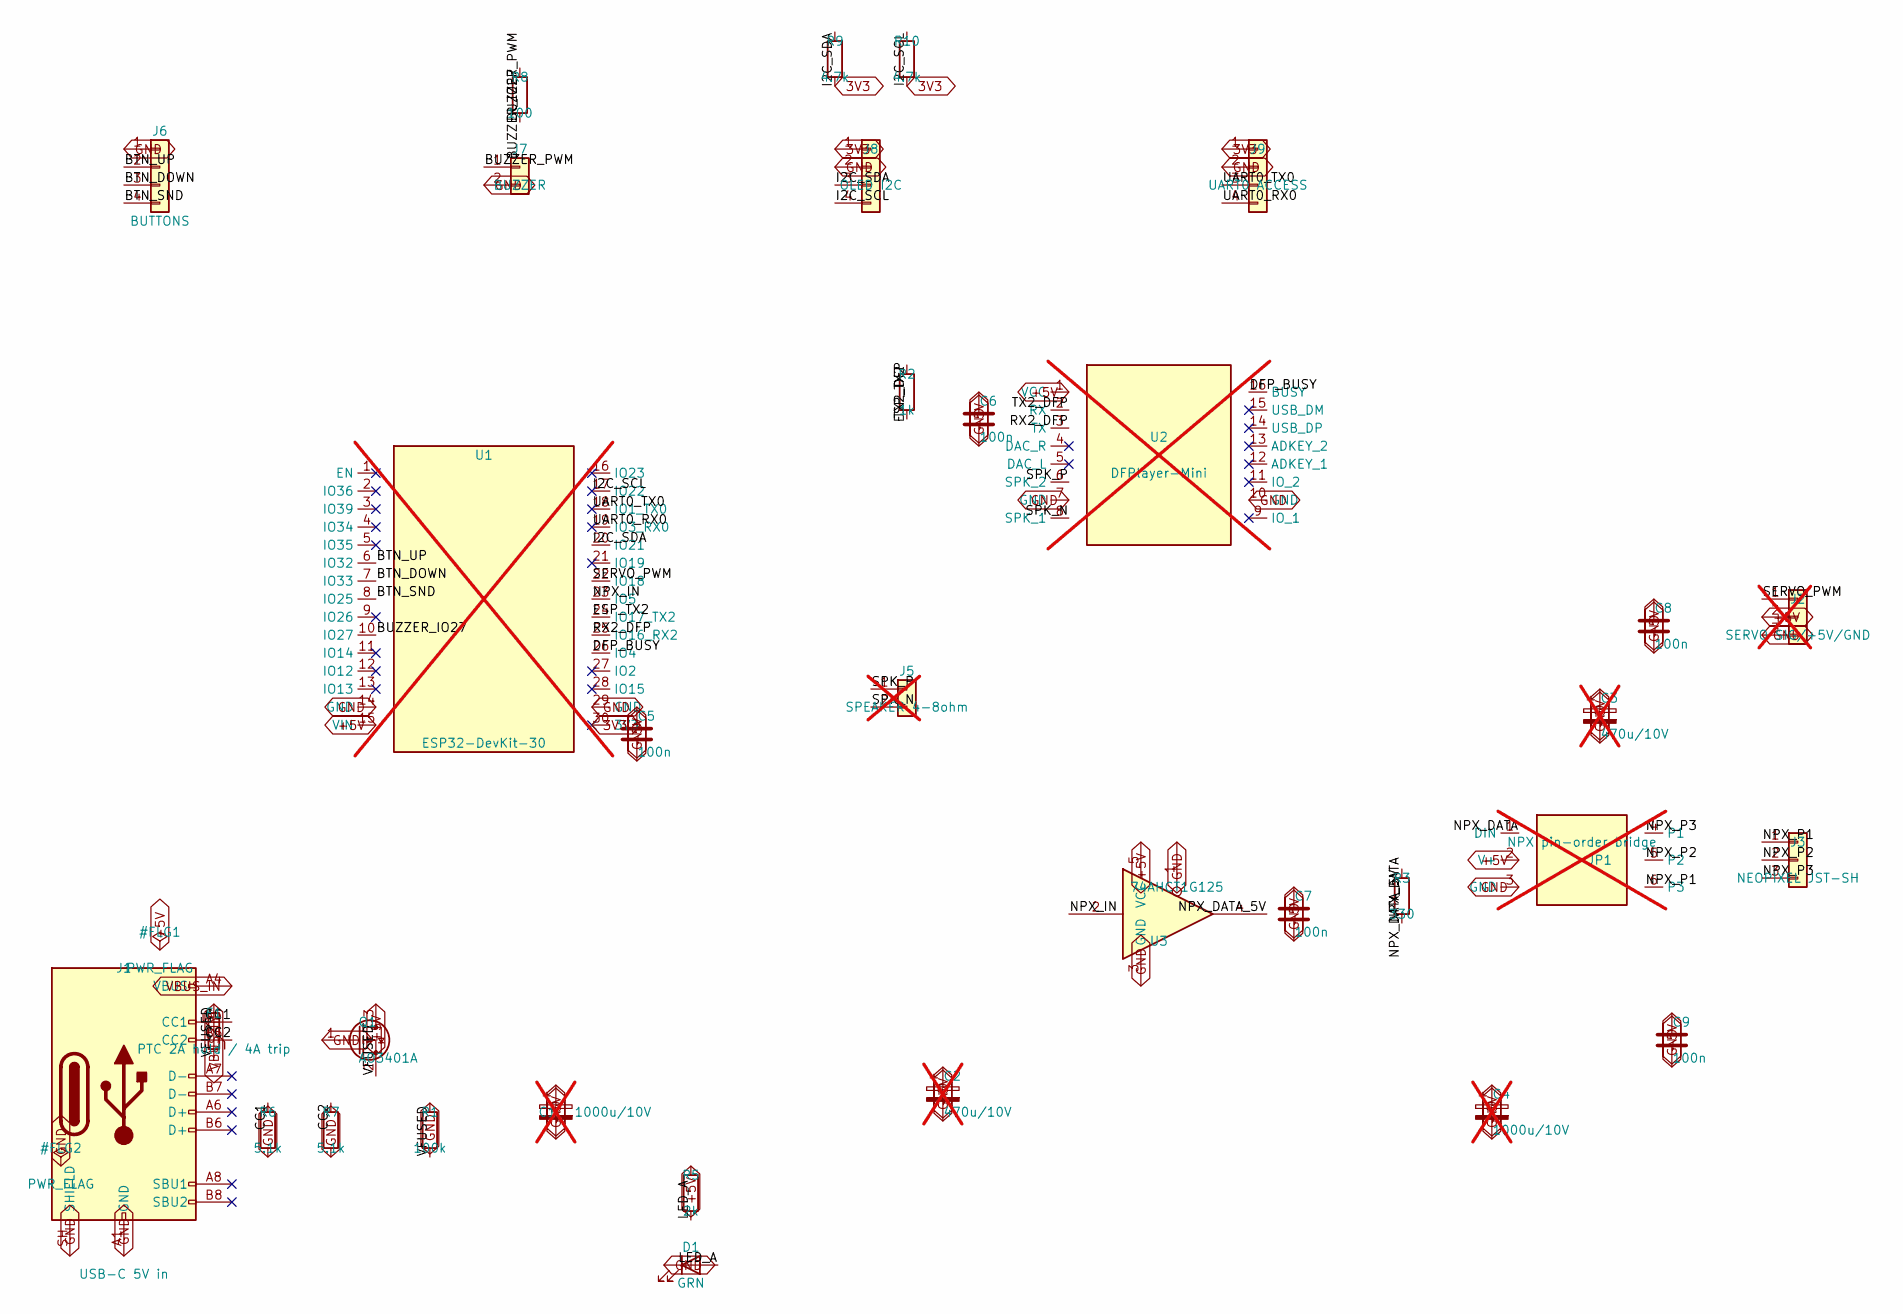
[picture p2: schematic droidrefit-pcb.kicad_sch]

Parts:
C1, C4: 1000u/10V; CP_Elec_8x10.5; MPN RVE1A102M0810; LCSC C310838; not fitted
C2, C3: 470u/10V; CP_Elec_6.3x7.7; MPN RVT1A471M0607; LCSC C335982; not fitted
C5, C6, C7, C8, C9: 100n; C_0603_1608Metric; MPN CC0603KRX7R9BB104; LCSC C14663
D1: GRN; LED_0603_1608Metric; MPN XL-1608UGC-04; LCSC C965804
F1: PTC 2A hold / 4A trip; Fuse_1812_4532Metric; MPN 1812L200/30GR; LCSC C18198342
J1: USB-C 5V in; USB_C_Receptacle_HCTL_HC-TYPE-C-16P-01A; MPN TYPE-C 16PIN 2MD; LCSC C2765186
J2: SERVO SIG/+5V/GND; PinHeader_1x03_P2.54mm_Vertical; MPN 1x3 2.54mm header; LCSC C49257; not fitted
J3: NEOPIXEL JST-SH; JST_SH_BM03B-SRSS-TB_1x03-1MP_P1.00mm_Vertical; MPN BM03B-SRSS-TB(LF)(SN); LCSC C160389
J5: SPEAKER 4-8ohm; JST_PH_B2B-PH-K_1x02_P2.00mm_Vertical; MPN B2B-PH-K-S; LCSC C131337; not fitted
J6: BUTTONS; PinHeader_1x04_P2.54mm_Vertical
J7: BUZZER; PinHeader_1x02_P2.54mm_Vertical
J8: OLED I2C; PinHeader_1x04_P2.54mm_Vertical
J9: UART0 ACCESS; PinHeader_1x04_P2.54mm_Vertical
JP1: NPX pin-order bridge; NeoPixel_Cfg_BridgeField_6; not fitted
Q1: AO3401A; SOT-23; MPN AO3401A; LCSC C15127
R1: 100k; R_0603_1608Metric; MPN 0603WAF1003T5E; LCSC C25803
R2: 1k; R_0603_1608Metric; MPN 0603WAF1001T5E; LCSC C21190
R3: 330; R_0603_1608Metric; MPN 0603WAF3300T5E; LCSC C23138
R5: 2k; R_0603_1608Metric; MPN 0603WAF2001T5E; LCSC C22975
R6, R7: 5.1k; R_0603_1608Metric; MPN 0603WAF5101T5E; LCSC C23186
R8: 100; R_0603_1608Metric
R9, R10: 4.7k; R_0603_1608Metric
U1: ESP32-DevKit-30; ESP32_DevKit_30pin_Socket_24p5mm; not fitted
U2: DFPlayer-Mini; DFPlayer_Mini_Socket; not fitted
U3: 74AHCT1G125; SOT-23-5; MPN SN74AHCT1G125DBVR; LCSC C7484

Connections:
3V3: J8.1, J9.1, R9.2, R10.2, U1.30 (3V3)
+5V: C1.1, C2.1, C3.1, C4.1, C5.1, C6.1, C7.1, C8.1, C9.1, J2.2, JP1.2 (V+), Q1.3 (D), R5.1, U1.15 (VIN), U2.1 (VCC), U3.5 (VCC)
BTN_DOWN: J6.3, U1.7 (IO33)
BTN_SND: J6.4, U1.8 (IO25)
BTN_UP: J6.2, U1.6 (IO32)
BUZZER_IO27: R8.1, U1.10 (IO27)
BUZZER_PWM: J7.1, R8.2
CC1: J1.A5 (CC1), R6.1
CC2: J1.B5 (CC2), R7.1
DFP_BUSY: U1.26 (IO4), U2.16 (BUSY)
ESP_TX2: R2.1, U1.24 (IO17_TX2)
GND: C1.2, C2.2, C3.2, C4.2, C5.2, C6.2, C7.2, C8.2, C9.2, D1.1 (K), J1.A1 (GND), J1.A12 (GND), J1.B1 (GND), J1.B12 (GND), J1.SH (SHIELD), J2.3, J6.1, J7.2, J8.2, J9.2, JP1.3 (GND), Q1.1 (G), R1.1, R6.2, R7.2, U1.14 (GND), U1.29 (GND), U2.7 (GND), U2.10 (GND), U3.1, U3.3 (GND)
I2C_SCL: J8.4, R10.1, U1.17 (IO22)
I2C_SDA: J8.3, R9.1, U1.20 (IO21)
LED_A: D1.2 (A), R5.2
NPX_DATA: JP1.1 (DIN), R3.2
NPX_DATA_5V: R3.1, U3.4
NPX_IN: U1.23 (IO5), U3.2
NPX_P1: J3.1, JP1.6 (P3)
NPX_P2: J3.2, JP1.5 (P2)
NPX_P3: J3.3, JP1.4 (P1)
RX2_DFP: U1.25 (IO16_RX2), U2.3 (TX)
SERVO_PWM: J2.1, U1.22 (IO18)
SPK_N: J5.2, U2.8 (SPK_1)
SPK_P: J5.1, U2.6 (SPK_2)
TX2_DFP: R2.2, U2.2 (RX)
UART0_RX0: J9.4, U1.19 (IO3_RX0)
UART0_TX0: J9.3, U1.18 (IO1_TX0)
VBUS_IN: F1.1, J1.A4 (VBUS), J1.A9 (VBUS), J1.B4 (VBUS), J1.B9 (VBUS)
VFUSED: F1.2, Q1.2 (S), R1.2

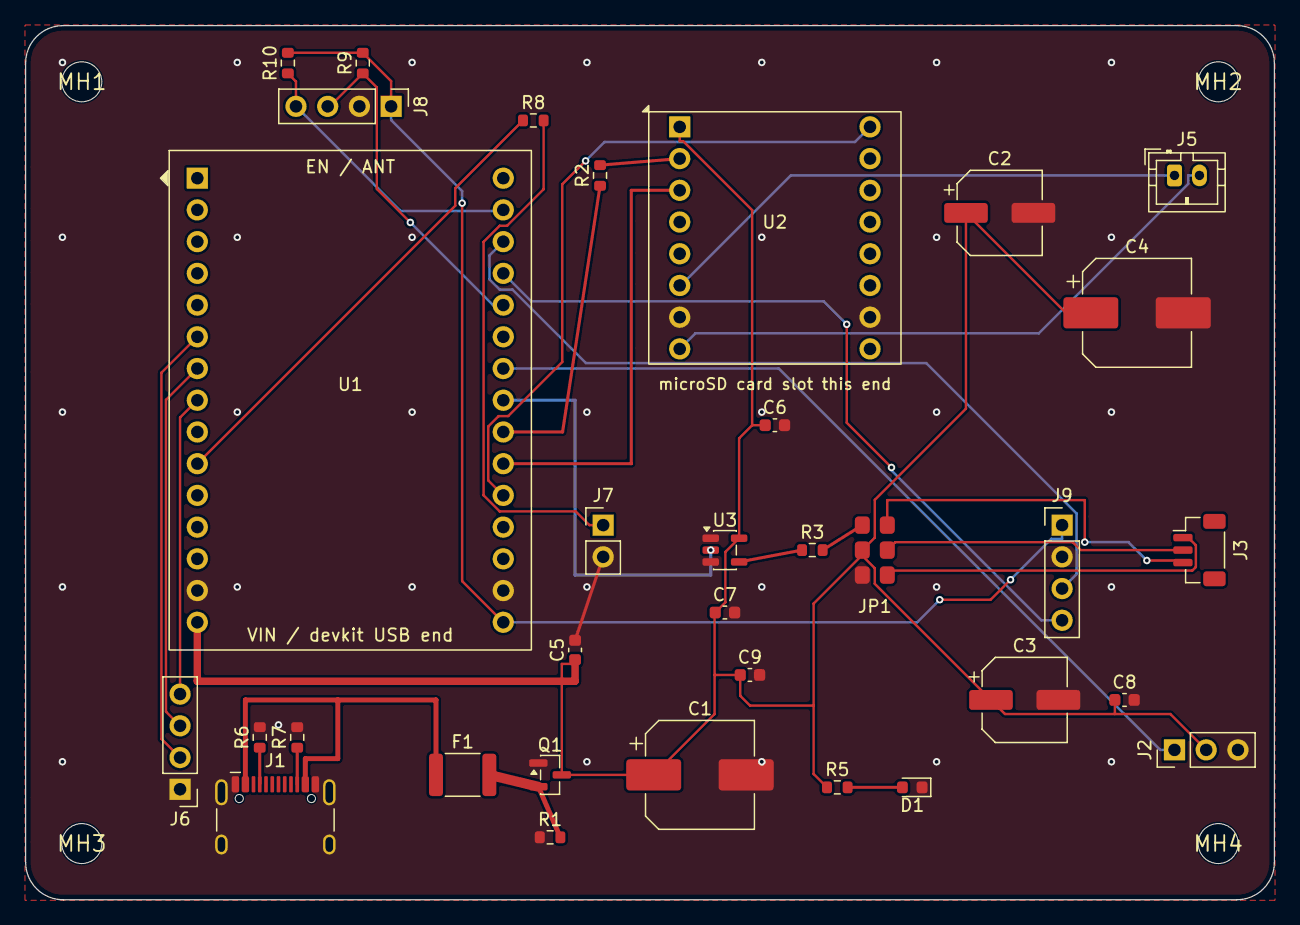
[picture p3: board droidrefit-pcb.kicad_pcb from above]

Board: 2 copper layers, 100.0 x 70.0 mm, 37 parts (0 on the bottom side), 30 nets.

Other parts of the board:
MH1, MH2, MH3, MH4: MountingHole_3.2mm

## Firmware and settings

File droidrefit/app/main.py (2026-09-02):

# Orchestrator: load config, wire the modules, run the task set.
# Entry point is /main.py -> app.main.run().

import os
import time
import machine
import uasyncio

# ---- Config / boot branch ----
# app.config always returns a usable dict now (offline defaults when there's no
# /config.json). WiFi/MQTT only run when cfg["network_enabled"]. The setup
# portal is reached on demand: buttons.button_task (hold Sound ~5s) or the
# factory-reset hold writes /portal.flag and resets; we run the blocking AP
# portal here, before the async app starts.
from app import config

cfg = config.load()

try:
    os.stat("/portal.flag")
    os.remove("/portal.flag")
    import app.provisioning as _provisioning
    _provisioning.run(config.device_id())      # blocks; machine.reset() on save
except OSError:
    pass

# core.init() must run before anything reads core.cfg. Import order below is
# deliberate: core first, then the feature modules (control before net/buttons).
from app import core
core.init(cfg)

from app import hw, sound, servo, leds, diag, ota, control, net, buttons, display

diag.log_boot()   # reset cause + free heap, first line after config


# ---- Factory-reset button ----
# The devkit's BOOT button is on GPIO0. Held LOW for RESET_HOLD_WIPE_MS while
# the firmware runs -> wipe /config.json and reboot into the setup portal, no
# password needed. GPIO0 is a strapping pin, so this is a while-running gesture
# only — a hold-at-boot would drop the ROM into serial-download mode instead.
RESET_HOLD_WIPE_MS = 10000


async def reset_button_task():
    held_since = None
    warned = False
    while True:
        if hw.reset_btn.value() == 0:  # active-low: pressed
            now = time.ticks_ms()
            if held_since is None:
                held_since = now
                warned = False
            else:
                held = time.ticks_diff(now, held_since)
                if held >= RESET_HOLD_WIPE_MS:
                    core.log_always("[reset] wiping config, rebooting into setup portal")
                    try:
                        sound.player.play_folder_track(6, 1)  # scream = "resetting"
                    except Exception:
                        pass
                    await uasyncio.sleep_ms(1500)
                    config.wipe()
                    try:
                        open("/portal.flag", "w").close()
                    except OSError:
                        pass
                    machine.reset()
                elif not warned and held >= 3000:
                    core.log_always("[reset] keep holding %ds to wipe config"
                                    % (RESET_HOLD_WIPE_MS // 1000))
                    warned = True
        else:
            held_since = None
        await uasyncio.sleep_ms(100)


async def main():
    net_on = bool(core.cfg.get("network_enabled"))
    mqtt = net_on and bool(core.cfg.get("mqtt_enabled"))

    if not net_on:
        core.log_always("[boot] offline — hold the Sound button ~5s for WiFi setup")
    elif mqtt:
        # A broker that's down at boot must not brick the board — flag the link
        # down and let connection_watchdog bring it up when the broker returns.
        try:
            await net.establish_link()
        except Exception as e:
            core.log_always("[boot] MQTT link failed, watchdog will retry:", e)
            core.link_state["down"] = True
    else:
        await net.connect_wifi()   # join WiFi + NTP; no broker

    # Reaching main() at all means every module imported — good enough as the
    # "the new build works" signal. Clear any OTA rollback state.
    ota.confirm()

    sound.player.select_tf_card()
    sound.player.set_volume(core.state["volume"])

    tasks = [
        core.supervise("servo_task", servo.servo_task),
        core.supervise("led_task", leds.led_task),
        core.supervise("busy_monitor_task", sound.busy_monitor_task),
        core.supervise("mood_sound_task", sound.mood_sound_task),
        core.supervise("button_task", buttons.button_task),
        core.supervise("reset_button_task", reset_button_task),
        core.supervise("display_task", display.display_task),
        core.supervise("log_task", core.log_task),
    ]
    if mqtt:
        tasks += [
            core.supervise("mqtt_task", net.mqtt_task),
            core.supervise("state_publish_task", net.state_publish_task),
            core.supervise("heartbeat_task", net.heartbeat_task),
            core.supervise("diag_task", net.diag_task),
            core.supervise("connection_watchdog", net.connection_watchdog),
        ]
    if mqtt and ota.enabled():
        tasks.append(core.supervise("ota_boot_check", _ota_boot_check))
    await uasyncio.gather(*tasks)


async def _ota_boot_check():
    # one-shot: check the mirror for a newer version a few seconds after boot
    # (establish_link already wired ota._on_change when MQTT is on). Never
    # auto-installs. Then idle forever — supervise keeps the coro alive.
    await uasyncio.sleep_ms(8000)
    try:
        await ota.check()
    except Exception as e:
        core.dbg("[ota] boot check failed:", e)
    while True:
        await uasyncio.sleep_ms(3600000)


def run():
    uasyncio.run(main())

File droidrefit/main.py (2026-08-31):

# /main.py — entry point (must live at the flash root; the runtime runs it
# after boot.py). All real code is the `app` package; third-party libs in /lib.
# This file and boot.py are NOT touched by OTA (app/ + lib/ only), so the
# bootstrap and the rollback below are always known-good.
import sys
import os
import time

if "/lib" not in sys.path:
    sys.path.append("/lib")


# --- OTA rollback -----------------------------------------------------------
# app/ota.py leaves /ota.flag after downloading a new build and backs the old
# files up to /bak. If the new build can't boot cleanly a few times running,
# restore /bak. Plain file ops only — the fresh app/ might be broken.
def _rmtree(p):
    try:
        for e in os.ilistdir(p):
            c = p + "/" + e[0]
            _rmtree(c) if (e[1] & 0x4000) else os.remove(c)
        os.rmdir(p)
    except OSError:
        pass


def _restore(bak, dst):
    try:
        entries = list(os.ilistdir(bak))
    except OSError:
        return
    for name, typ, *_ in entries:
        src = bak + "/" + name
        tgt = dst + "/" + name
        if typ & 0x4000:
            try:
                os.mkdir(tgt)
            except OSError:
                pass
            _restore(src, tgt)
        else:
            with open(src, "rb") as fi:
                with open(tgt, "wb") as fo:
                    while True:
                        b = fi.read(512)
                        if not b:
                            break
                        fo.write(b)


try:
    import json as _json
    import machine as _machine
    with open("/ota.flag") as _f:
        _ota = _json.load(_f)
    _ota["boots"] = _ota.get("boots", 0) + 1
    with open("/ota.flag", "w") as _f:
        _json.dump(_ota, _f)
    if _ota["boots"] > 2:
        print("[ota] new build failed %d boots — rolling back" % _ota["boots"])
        _restore("/bak", "")
        try:
            os.remove("/ota.flag")
        except OSError:
            pass
        _rmtree("/bak")
        _machine.reset()
except OSError:
    pass


# --- recovery hatch, checked before the app starts ---
# /noboot.txt sentinel file: hard skip. Create it from the REPL
#      open("noboot.txt", "w").close()
#    reset -> clean REPL. Remove it
#      os.remove("noboot.txt")
#    and reset to run normally. (tools/deploy.py manages this file for you.)
_skip = False
try:
    os.stat("noboot.txt")
    _skip = True
    print("\n" + "=" * 54)
    print("  SAFE MODE  —  noboot.txt present, app NOT started")
    print("  run normally:  import os; os.remove('noboot.txt')  then reset")
    print("=" * 54 + "\n")
except OSError:
    pass

if not _skip:
    try:
        from app.main import run
        run()
    except KeyboardInterrupt:
        raise
    except Exception as _e:
        sys.print_exception(_e)
        # If an OTA trial is in flight (/ota.flag present), a crash here has to
        # become a reset so the boot counter in /main.py's rollback block can
        # climb to the rollback threshold. Without a normal OTA in progress a
        # crash is just a bug — stay at the REPL so it's debuggable over USB.
        try:
            os.stat("/ota.flag")
        except OSError:
            raise
        print("[ota] new build crashed on boot — resetting to advance rollback")
        import machine
        time.sleep(3)
        machine.reset()

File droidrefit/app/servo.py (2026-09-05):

# Servo motion: one rate-limited driver, modes as setpoint generators.
#
# servo_task is the ONLY thing that touches the servo. Each tick it asks the
# current behaviour "where should the head be?" and eases `pos` toward that
# under SERVO_MAX_ACCEL / per-behaviour speed limits. Because `pos` can only
# change by vel*dt and `vel` by accel*dt, the PWM output can never jump or
# spike — so switching modes mid-move is just a smooth setpoint redirect, no
# cancellation, no position/velocity discontinuity. Behaviours are plain state
# machines: target(now, pos) -> (setpoint_deg, max_speed_deg_s); recreated on
# every mode change.
#
# deps: app.core, app.hw

import math
import time
import machine
import uasyncio

from app import core, hw

# --- PWM signal params ---
MIN_US = 500
MAX_US = 2500
PERIOD_US = 1_000_000 // hw.SERVO_FREQ

SWEEP_MIN = 1
SWEEP_MAX = 179

# A servo samples its commanded position once per PWM period (20ms @ 50Hz) —
# the finest tick that means anything physically.
TICK_MS = 20
TICK_S = TICK_MS / 1000

# --- motion envelope ---
SERVO_MIN_ANGLE = 0
SERVO_MAX_ANGLE = 180
SERVO_MAX_ACCEL = 1200   # deg/s^2 — accel + decel ramp; main "snappy vs jerky" knob
ARRIVE_EPS = 1.0         # deg — "close enough" to count as arrived and stop

# Per-behaviour cruise speeds (deg/s). Old sweeps were ms/deg:
# alert 10 -> 100, surveillance 30 -> 33, wander 40 -> 25.
SPEED_ALERT = 100
SPEED_SURVEIL = 33
SPEED_WANDER = 25
SPEED_TREMBLE = 200
SPEED_SETTLE = 90


def angle_to_duty_u16(angle):
    pulse_us = MIN_US + (angle / 180) * (MAX_US - MIN_US)
    return int(pulse_us / PERIOD_US * 65535)


# Built here (not in app.hw) so it starts already centred at 90 — no duty-0
# twitch. core.servo_state["angle"] is the matching software estimate.
servo = machine.PWM(machine.Pin(hw.SERVO_PIN), freq=hw.SERVO_FREQ,
                    duty_u16=angle_to_duty_u16(90))


def _clamp(x, lo, hi):
    return lo if x < lo else (hi if x > hi else x)


def _approach(pos, vel, setpoint, max_vel, max_accel, dt):
    # Trapezoidal-velocity move toward `setpoint`: ramp `vel` toward the fastest
    # speed from which we can still brake to a stop exactly on arrival
    # (v = sqrt(2*a*d)), accel-limited both ways. Snaps to the target on the
    # final tick so discrete stepping can't overshoot. `max_accel` is per-move
    # (a behaviour can crack harder than the SERVO_MAX_ACCEL default).
    err = setpoint - pos
    dist = abs(err)
    if dist < ARRIVE_EPS and abs(vel) < ARRIVE_EPS:
        return setpoint, 0.0
    v_brake = math.sqrt(2 * max_accel * dist)
    v_cap = v_brake if v_brake < max_vel else max_vel
    v_des = v_cap if err > 0 else -v_cap
    dv_max = max_accel * dt
    dv = _clamp(v_des - vel, -dv_max, dv_max)
    vel += dv
    step = vel * dt
    if abs(step) >= dist:
        return setpoint, 0.0
    return pos + step, vel


def _pick_target(pos, min_travel=30):
    # A random angle in the sweep range at least `min_travel` deg from `pos`,
    # so a "wander" move is always a visible one. Bounded retry, then give up.
    target = core.rand_between(SWEEP_MIN, SWEEP_MAX)
    for _ in range(10):
        if abs(target - pos) >= min_travel:
            break
        target = core.rand_between(SWEEP_MIN, SWEEP_MAX)
    return target


class _Hold:
    # Ease to a fixed angle and stay. Modes: sleep, hologram.
    def __init__(self, angle, speed=SPEED_SETTLE):
        self.angle = angle
        self.speed = speed

    def target(self, now, pos):
        return self.angle, self.speed


class _Dart:
    # Snappy darts to random spots with a pause between; `double_pct` chance of
    # an immediate second dart ("double-take") before the next pause. Returns a
    # 3-tuple so it can crack harder than the default accel. Modes: alert
    # (measured), excited (frantic).
    def __init__(self, speed, accel, wait_min, wait_max, double_pct,
                 name="dart", min_travel=45):
        self.speed = speed
        self.accel = accel
        self.wait_min = wait_min
        self.wait_max = wait_max
        self.double_pct = double_pct
        self.name = name
        self.min_travel = min_travel
        self.goal = None
        self.phase = "wait"       # wait -> dart -> [dart again] -> wait ...
        self.until = None
        self.doubles = 0

    def target(self, now, pos):
        if self.goal is None:
            self.goal = pos
        if self.phase == "wait":
            if self.until is None:
                self.until = time.ticks_add(
                    now, core.rand_ms(self.wait_min, self.wait_max))
            elif time.ticks_diff(now, self.until) >= 0:
                self.goal = _pick_target(pos, self.min_travel)
                self.phase, self.until, self.doubles = "dart", None, 0
                core.dbg("[servo]", self.name, "dart ->", self.goal)
        elif self.phase == "dart":
            if abs(pos - self.goal) < ARRIVE_EPS:
                if self.doubles < 2 and core.rand_between(0, 99) < self.double_pct:
                    self.doubles += 1
                    self.goal = _pick_target(pos, 22)
                    core.dbg("[servo]", self.name, "double-take ->", self.goal)
                else:
                    self.phase, self.until = "wait", None
        return self.goal, self.speed, self.accel


class _Sweep:
    # Oscillate lo<->hi forever at a fixed speed. Flips a hair before the end
    # so the turnaround rounds off instead of stopping dead. Mode: surveillance.
    def __init__(self, lo, hi, speed):
        self.lo = lo
        self.hi = hi
        self.speed = speed
        self.goal = hi

    def target(self, now, pos):
        if abs(pos - self.goal) < 2.0:
            self.goal = self.lo if self.goal == self.hi else self.hi
            core.dbg("[servo] sweep ->", self.goal)
        return self.goal, self.speed
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

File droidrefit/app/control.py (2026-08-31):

# The single control path — every input surface (MQTT, the setup portal, the
# front-panel buttons) funnels mode / sound / volume changes through here.
# Just sets core.state[...] and fires the side effect; servo_task and led_task
# react to state, sound plays immediately. No network here.
#
# deps: app.core, app.sound, app.servo

from app import core, sound, servo

# Order the mode ▲/▼ buttons step through. system_crash is a transient reaction
# (auto-reverts), not a resting mode — reachable from Home Assistant, not the
# button cycle.
MODE_CYCLE = ("standby", "awake", "excited", "surveillance",
              "alert", "hologram", "sleep")


def apply_mode(mode):
    if mode not in servo.SERVO_BEHAVIORS:
        return False
    if mode != core.state["mode"]:
        core.log_always("[mode]", mode)
    core.state["mode"] = mode
    return True


def cycle_mode(step):
    """Step the current mode +1 / -1 through MODE_CYCLE, wrapping."""
    cur = core.state["mode"]
    try:
        i = MODE_CYCLE.index(cur)
    except ValueError:
        i = 0                       # currently in a mode outside the cycle (e.g. system_crash)
        step = 0
    nxt = MODE_CYCLE[(i + step) % len(MODE_CYCLE)]
    return apply_mode(nxt)


def apply_sound(name):
    if name not in sound.SOUND_FOLDERS:
        return False
    core.log_always("[sound]", name)
    core.state["sound"] = name
    sound.play_random_in_folder(name)
    return True


def play_any_sound():
    """A random category — what the front-panel Sound button fires."""
    cats = list(sound.SOUND_FOLDERS.keys())
    return apply_sound(cats[core.rand_between(0, len(cats) - 1)])


def apply_volume(level):
    try:
        level = int(level)
    except (ValueError, TypeError):
        return False
    level = max(0, min(30, level))
    if level != core.state["volume"]:
        core.log_always("[volume]", level)
    core.state["volume"] = level
    sound.player.set_volume(level)
    return True


def nudge_volume(step):
    """Bump volume by step, clamped 0-30. Returns the new level."""
    new = max(0, min(30, core.state["volume"] + step))
    apply_volume(new)
    return new

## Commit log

2026-08-31 Initial storage of the git deployable code. Planning on from device updates.
2026-08-31 Storing current chagnes
2026-08-31 Restructure for the plain-ESP32 astromech-homeassistant build
    Rewrite docs around the current firmware (modular app/, portal, web panel,
    OTA, diagnostics); retire the CyberBrick README to docs/cyberbrick-origins.md.
    Add the carrier PCB (hardware/) and tools/deploy.py. Rename OTA source repo
    CyberBrick-HomeAssistant-MQTT -> astromech-homeassistant.
    [droidrefit-pcb-BOM-JLC.csv, droidrefit-pcb-BOM-full.csv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]
2026-08-31 OTA: reset on boot crash while a trial is in flight so rollback can trigger
    Root main.py's rollback counts boots in /ota.flag but nothing advanced the
    counter when a bad build failed to import/start — it just fell to the REPL.
    Now a crash with /ota.flag present resets (up to the rollback threshold);
    a crash with no OTA in progress still stops at the REPL for USB debugging.
    [main.py]
2026-08-31 OTA: hard gc + free-heap logging before every TLS call
    check() was hitting ENOMEM on classic ESP32 even for the tiny version.py
    fetch. Collect twice and log gc.mem_free() before check / manifest / install
    so we can see how close to the wall we are.
2026-08-31 OTA: HTTP-mirror download path (no TLS) for classic ESP32
    GitHub-direct TLS fails ENOMEM on a classic ESP32 even with ~67 KB free —
    mbedTLS needs ~16 KB contiguous blocks and MicroPython's GC doesn't compact.
    Add core.cfg['ota_url']: when set, check + update pull plain HTTP from that
    mirror, file by file, staged as <path>.ota then renamed once all arrive so a
    mid-download failure can't corrupt the running build. mip/GitHub stays the
    default for roomier targets. Offline-tested (happy path + mid-download fail).
    [config.py, ota.py]
2026-08-31 Remove accidentally-committed device config backup; gitignore the pattern
2026-08-31 deploy.py: safe-mode staging + per-file SHA verify + retry
    The old tool copied ~18 files in one chained mpremote call; on a flaky USB
    link a truncated/failed copy stopped the chain and aborted the run (a
    truncated net.py once caused a SyntaxError on the board). Now:
    - hold the board in safe mode (noboot.txt + reset) for the whole copy so the
    app isn't running and nothing competes for the link
    - copy each file, SHA-256-verify it on the device, re-copy on mismatch
    (4 tries/file), and retry the mpremote calls themselves
    - only remove noboot.txt + reboot once every file verifies and the import
    check passes; a failed/interrupted run leaves the board at a safe REPL and
    re-running converge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
    [deploy.py]
2026-08-31 Remove the 2s Ctrl-C boot countdown
    A stray byte on the serial line during the countdown (some terminals/USB
    hosts send one on connect) reads as Ctrl-C and drops the board to the REPL
    instead of starting the app — a non-deterministic first-boot failure. noboot.txt
    (now also managed by deploy.py) is the deliberate 'give me a clean REPL' hatch;
    the countdown was redundant. Ctrl-C still drops out of a running app.
    [main.py]
2026-08-31 Note that the board needs a hard power-cycle after flashing
    deploy.py ends with a soft reset, but hardware timers / UART / PWM / singleton
    driver objects survive that — only a cold boot matches the state the firmware
    runs in. Note in the README and printed at the end of deploy.py.
    [deploy.py]
2026-08-31 Web server survives WiFi drops; close sockets on reconnect; overnight serial logger
    Diagnosing an R2 unit that rebooted at ~2am and left its web panel dead while
    MQTT stayed up (task_restarts=0, so nothing crashed):
    - webui.web_server_task no longer awaits _server.wait_closed() (hangs forever if
    start_server's accept loop wedges after a WiFi drop — no crash, so supervise
    can't help). It now rebuilds the listener whenever the network re-associates,
    tracked by core.net_generation, and _close_server() times out instead of
    hanging on a wedged server.
    - net.wifi_monitor_task catches the ESP32's silent auto-reconnects (2s poll,
    False->True edge) and bumps net_generation; connect_wifi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
    [core.py, diag.py, main.py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]
2026-08-31 Offline-first: 3 front-panel buttons, remove the web control panel
    The droid now boots and runs standalone. Physical buttons are the primary
    control; WiFi + Home Assistant are an optional layer, off by default.
    - app/buttons.py — mode up / mode down / sound on GPIO32/33/25 (pin<->GND,
    internal pull-up). Mode buttons step control.MODE_CYCLE (7 resting modes)
    with auto-repeat; sound taps a clip, or a ~5s hold writes /portal.flag and
    reboots into the WiFi setup portal.
    - app/control.py — apply_mode/apply_sound/apply_volume + cycle_mode moved out
    of net.py into a leaf module; buttons, MQTT and the portal all call it.
    - config: network_enabled (default False) gates all WiFi/MQTT. con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
    [buttons.py, config.py, control.py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]
2026-08-31 Buttons v2: volume on hold, piezo buzzer feedback, hardened portal trigger
    - app/fx.py (new): piezo buzzer on GPIO27 (machine.PWM). Cues: volume tick
    (pitch tracks level), mode blip, portal-entry chirp, saved/error. No-op when
    buzzer_enabled is false or PWM init fails.
    - Mode buttons: tap (<0.5s) = cycle reaction; press-and-hold = volume +/-1
    every 0.25s with a tick each step. Drops the old hold-to-spin auto-repeat.
    - Portal trigger is now the two-button chord Mode up + Sound held 5s (a lone
    button can't do it by accident). Lone Sound is just tap-for-a-clip now.
    - provisioning: self-heals — reboots back into the app after 5 min with nobody
    connected to the AP; a /cancel link exit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
    [buttons.py, config.py, control.py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]
2026-08-31 PCB: add J_OLED header (SSD1306 128x64 I2C on IO21/22, 3V3)
    Also wire the devkit 3V3 pin (was no-connect) to J_OLED pin 1 — the onboard
    AMS1117 powers the ~20mA display. Note 4.7k I2C pull-ups. Firmware will
    auto-detect the OLED (no display = no cost).
2026-08-31 PCB: add J_UART header + 'updating a boxed unit' notes
    The carrier's USB-C is power-only (no data, no USB-serial chip). J_UART
    (3V3/GND/TX0/RX0) lets a USB-TTL cable do deploy.py/serial on a boxed unit
    without opening it. Also documents the three update paths: J_UART, devkit
    Micro-USB via a box cutout, or OTA.
2026-09-01 docs: add DFPlayer reference (docs/dfplayer.md)
    SD-card layout, the 7 mood folders, how to add clips (drop file + bump the
    SOUND_FOLDERS count + deploy), the serial command/query tables, clone-chip
    caveats, and why the BUSY pin is used instead of track-finished events. Also
    records the three ways folder counts could be made self-sizing later (each
    needs reply-frame parsing in dfplayer.py first). No code change.
2026-09-01 SSD1306 OLED: status screen + portal AP details
    - lib/ssd1306.py — vendored MicroPython driver (MIT, I2C-only trim).
    - app/oled.py — leaf (machine + ssd1306). open() scans I2C0 on GPIO21/22 for
    0x3C/0x3D and returns an SSD1306_I2C or None. No core dep, so provisioning
    can use it too.
    - app/display.py — display_task (always-on): auto-detect; none -> idle. Shows
    device name / mode / volume bar / now-playing / net line, redraw on change.
    - provisioning.py — the portal draws the AP name/password/URL on the OLED, and
    a 'Saved, restarting' screen. Best-effort, never fails the portal.
    - Registered in main.py task list, __init__ DAG, package.json, deploy.py.
    Auto-detect, no config f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
    [deploy.py, display.py, main.py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]
2026-09-01 OLED: status line — what the head is doing while wandering
    servo_task now writes core.servo_state['moving'] (|vel| > 0.5 deg/s). The
    display status line shows the playing sound, or while the servo is actively
    moving a per-mode verb: standby/surveillance -> 'scanning...', awake ->
    'watching...', excited -> 'bouncing...', etc. Hold modes (sleep/hologram)
    stay blank.
2026-09-01 servo: 'excited' is now dart-and-pause, not a sweep
    _approach() takes a per-move max_accel (behaviours may return a 3-tuple
    (setpoint, speed, accel); the rest still return 2-tuples -> SERVO_MAX_ACCEL).
    New _Excited: waits 1.5-3.5s, then cracks to a random spot at 150 deg/s /
    2200 deg/s^2 (vs the 1200 default), and ~40% of the time immediately does a
    short second dart ('double-take') before the next pause. Reads as reacting to
    things rather than a metronome. OLED verb 'bouncing' -> 'darting'.
    Offline sim: 12 darts / 3 double-takes in 30s, peak vel capped at 150,
    accel-limited mid-flight, no overshoot, 1.5-3.5s pauses. _Sweep regression ok.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
    [display.py, servo.py]
2026-09-01 supervise: back off + log when a task returns (not just when it crashes)
    The chatty '[display] SSD1306 up' x17-in-1ms = display_task returning and
    supervise re-spawning it with no delay (the sleep was only in the except
    branch). Now: 2s backoff on BOTH return and crash, both logged via log_always
    (so a misbehaving task is visible without the debug switch). display_task also
    wraps its whole loop body in try/except and retries oled.open() every 30s
    instead of falling through.
    [core.py, display.py]
2026-09-01 oled: drop i2c.scan() — it froze the event loop ~19s on a weak bus
    scan() probes 112 addresses; on a bus with missing/weak pull-ups every probe
    times out (~170ms) and the whole ~19s blocks the asyncio loop (no servo,
    buttons, wifi). Now just try to init the panel directly at 0x3C/0x3D with a
    50ms I2C timeout — a missing panel fails on the first write, a present one
    comes up instantly. display_task retries 4x/2s at boot then goes quiet
    permanently instead of looping a log line.
    [display.py, oled.py]
2026-09-01 servo: _Dart behaviour — alert = measured darts, excited = frantic
    _Excited generalised to _Dart(speed, accel, wait_min, wait_max, double_pct,
    name, min_travel); double-take can chain up to 2.
    - alert -> _Dart(150, 2200, 1500, 3500, 40) (the previous 'excited' feel;
    alert was an edge-to-edge _Sweep before)
    - excited -> _Dart(260, 3400, 500, 1400, 70, min_travel=30) frantic
    surveillance keeps the smooth _Sweep. Sim-checked both param sets: speed
    capped, accel-limited, no overshoot.
    Note: excited at 260 deg/s is a real current spike — watch for brownout on a
    marginal supply.
    [servo.py]
2026-09-02 logs: collapse consecutive identical lines; display_task never returns
    core.log_always: a run of the same line prints once, then only at 8x/16x/32x/
    ... (so a stuck loop is still visible), then a 'repeated Nx' summary when a
    different line finally comes. Serial + MQTT both protected — no more floods.
    display_task: wrapped so it can NEVER return; any fault logs once and idles
    forever, so supervise (any version) can't re-spawn it in a loop.
    [core.py, display.py]
2026-09-02 display: back off a wedged I2C bus instead of hammering it
    'E i2c.master: I2C hardware timeout detected' floods when the OLED bus latches
    low (missing pull-ups, or a bumped wire) — every d.show() times out and
    ESP-IDF prints its own error each ~400ms. Now: after 3 consecutive render
    failures, log once, pause, and retry oled.open() every 30s until it recovers.
    [display.py]
2026-09-02 oled: I2C at 100kHz not 400kHz — more robust on a breadboard bus
    Cuts the transient 'I2C hardware timeout' glitches from wire capacitance /
    servo-lead noise. A status screen refreshing every ~400ms doesn't need 400kHz.
    [oled.py]
2026-09-02 HA-tunable moods: curated per-mood knobs + reset buttons
    Expose a small, behaviour-appropriate set of knobs per mood over MQTT so a
    mood can be reshaped from Home Assistant without a reflash:
    speed 0-100/50 -> cruise-speed multiplier knob/50, clamp 15-300 deg/s
    restlessness 0-100/50 -> _Wander/_Dart wait multiplier 50/knob, floor 200/400ms
    LED bright 0-200/100 -> per-mood pixel brightness multiplier, clamp 0-1
    _Wander/_Dart moods get all three; _Sweep/_Tremble get speed+bright; _Hold
    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
2026-09-02 net: fix MQTT discovery crash — MicroPython str has no .title()
    publish_discovery used "mood".replace("_"," ").title() for the tune entity
    names; .title() doesn't exist on the device, so establish_link raised
    'str object has no attribute title' and the link never came up. Replace with
    a local _title() helper.
    Caught by adding a publish_discovery smoke-test to test_import_chain.py.
    [net.py]
2026-09-02 net: one HA sub-device per mood so tuning gets a card each
    publish_discovery now emits each mood's knobs + reset button against a
    per-mood device ({identifiers:[<prefix>_<mood>], via_device:<prefix>}),
    linked to the droid. Home Assistant auto-generates a separate card per mood.
    unique_ids are unchanged, so HA just re-homes the existing entities.
    Entity names drop the mood prefix ("Speed", not "Excited Speed") since HA
    prefixes them with the sub-device name; entity_category "config" dropped so
    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
2026-09-02 Mood tuning: per-mood audio + auto-revert, populate the cards, fix slider lag
    Three related changes to the HA mood-tuning system, developed together (they
    share net.py so they land as one commit):
    1. Per-mood sub-device cards actually populate (finishes 82d8770). HA won't
    re-home an already-registered entity when only the discovery `device` block
    changes, so v2 publishes the knobs under fresh `<mood>_<knob>` topic/ids and
    clears the old `tune_<mood>_<knob>` (v1) discovery configs first.
    2. Per-mood audio + per-mood auto-revert duration:
    - `Audio` select (off + the 7 SOUND_FOLDERS categories) and `Audio Repeat (s)`
    number on every mood. sound.mood_sound_task (always running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
    [config.py, main.py, net.py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]
2026-09-05 LEDs: migrate every mood to the standby PSI/logic-display scheme; NeoPixel bring-up; deploy.py hard-reset + .mpy precompile
    - leds.py: PixelChannel gains `fade` (deterministic 2-colour cross-fade,
    breathe's easing on hue not brightness) and `fadeout` (one-shot decay to
    off) patterns; `twinkle` accepts a multi-colour palette list alongside the
    old 2-colour form. Pixels reframed per real R2 terminology: 0/2 are PSIs,
    1/3 are front/rear logic displays.
    - standby is now the template every other mood's lights are built from
    (front=blue family, rear=green family; differences are mainly transition
    speed + a small per-pixel personality tweak), and syncs to the servo's
    _Wander phase (se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
    [deploy.py, hw.py, leds.py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]
2026-09-05 PCB: add buttons/buzzer/OLED/UART headers, fix JP1 default pinout
    droidrefit-pcb respin closing gaps DESIGN.md had already speced but never
    drawn into the schematic/board:
    - New J6 (BUTTONS, 1x4: GND/IO32/IO33/IO25), J7 (BUZZER, 1x2: IO27 via a
    new R8 100ohm series/GND), J8 (OLED I2C, 1x4: 3V3/GND/SDA/SCL, with new
    R9/R10 4.7k pull-ups to 3V3), J9 (UART0 ACCESS, 1x4: 3V3/GND/TX0/RX0).
    All four wired straight to U1's existing free socket pins per the pin
    assignments DESIGN.md's own Connectors/firmware-pin-map tables already
    committed to. All dnp+hand-solder like J2/J5 (2.54mm headers, not
    JLC-placed); R8/R9/R10 are real JLC-placed SMD 0603s.
    - Fixed JP1 (NeoPixel pin-order solder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
    [droidrefit-pcb-BOM-JLC.csv, droidrefit-pcb-BOM-full.csv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]
2026-09-05 PCB: move J7 off the microSD card path, reroute NPX_P2 around J9 -> 0 DRC errors
    Follow-up to the header respin, two fixes:
    - J7 (buzzer header) was auto-placed at (52,32), directly in the DFPlayer's
    microSD card insertion/ejection path -- ~3mm south of the SD-slot edge,
    THT pins tall enough to foul a card or a plugged-in wire. Moved to
    (46.25,40), west of the card corridor; BUZZER_PWM re-routed.
    - The residual GND/NPX_P2 DRC short was J9 sitting in the JP1->J3 NeoPixel
    bundle: the straight NPX_P2 run at y=42 clipped J9's GND pad at (83,42.54).
    Rerouting P1/P3 around J9 by hand earlier had left P2 straight through.
    Let Freerouting route NPX_P2 (as it already had for P1); that al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
    [droidrefit-pcb-B_Cu.gbl, droidrefit-pcb-B_Mask.gbs, droidrefit-pcb-B_Paste.gbp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]
2026-09-05 PCB: move the 4 M3 mounting holes tighter into the corners
    The 7mm-inset positions had MH2's keepout ring overlapping J5's courtyard
    (a pre-existing body_overlap) and MH3/MH4 crowding the new J6 buttons
    header / the J2 servo header -- an M3 screw + washer at those corners would
    have fought a plugged-in connector.
    Moved all 4 to a symmetric 91 x 61 mm pattern, 4.5 mm in from each edge
    (4.5/4.5, 95.5/4.5, 4.5/65.5, 95.5/65.5). Now ~4mm clearance from a washer
    edge to the nearest connector pad at every corner. All mechanical
    overlaps gone; still 0 DRC errors. Enclosure is 3D-printed and designed
    around the holes, so the asymmetry-vs-components tradeoff went to
    clearance. Drill file + gerbers +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
    [droidrefit-pcb-B_Cu.gbl, droidrefit-pcb-B_Mask.gbs, droidrefit-pcb-B_Paste.gbp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]
2026-09-05 PCB: explicit GND trace to J7 pin 2
    KiCad GUI DRC flagged "Zone [GND] on F.Cu, priority 0 - missing
    connections" -- J7's GND pad, now sitting in the dense U1<->U2 channel
    after the SD-card-path move, isn't reliably reached by the GND pour on
    either layer in that tight pocket (the swig-backend DRC didn't catch it;
    the GUI's fill engine does). Added a short explicit GND trace from J7/2 to
    C5/2 so it no longer depends on the pour squeezing in there.
    Still 0 DRC errors here. Refill zones in the KiCad GUI (Edit -> Fill All
    Zones / B) after opening -- the swig zone fill and KiCad 9's GUI fill
    don't always agree, and the GUI's is authoritative.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
    [droidrefit-pcb.kicad_pcb]
2026-09-05 PCB: GND stitching via to reconnect an isolated F.Cu pour island
    kicad-cli DRC (--refill-zones, the same engine as the GUI) showed the real
    issue behind the "Zone [GND] on F.Cu missing connections" the swig-backend
    DRC kept missing: the F.Cu GND pour was fragmenting into islands. One
    island, walled off by the VBUS_IN/CC1/CC2 traces around J1, held R6/R7's
    GND pads (SMD, F.Cu-only) with no path back to the net. Added a GND
    stitching via at (20.25,56) inside that island, tying it to the
    continuous B.Cu GND pour.
    kicad-cli DRC now: 0 errors, 0 unconnected items. Zone fill regenerated
    with KiCad's own engine (--save-board) so the on-disk fill matches the GUI.
    Remaining warnings are cosmetic (U2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
    [droidrefit-pcb.kicad_pcb]
2026-09-05 PCB: GUI finishing pass - refill zones, sync U2 footprint, tidy JP1 label
    User's KiCad 10 session: Fill All Zones (B), Update Footprint from Library
    on U2 (clears the DFPlayer_Mini_Socket lib mismatch + fixes the stale descr
    that disagreed on which end the microSD slot is on), moved a JP1 silk
    label off a pad. .kicad_sch/.kicad_pro carry KiCad 10's file-format
    upgrade (20260101 -> 20260306) - benign.
    kicad-cli DRC on this state: 0 violations, 0 unconnected items. Only the
    8 cosmetic mounting-hole silk-over-pad warnings remain (JLC auto-clips).
    [droidrefit-pcb.kicad_pcb, droidrefit-pcb.kicad_sch]
2026-09-05 PCB: LCSC parts for R8/R9/R10, final fab package regen
    - R8 = C22775 (100 ohm 0603 1%, UNI ROYAL 0603WAF1000T5E, JLC Basic)
    - R9/R10 = C23162 (4.7k 0603 1%, UNI ROYAL 0603WAF4701T5E, JLC Basic)
    Same UNI ROYAL 0603WAFxxxxT5E family as R1-R7; both Basic, no extended fee.
    Added LCSC/MPN/Manufacturer/JLCPCB_Assembly props to the sch.
    - Full fab package regenerated via kicad-cli (GUI-parity engine) from the
    final board: gerbers + zip, drill + maps, 2d-top.png, fab-preview.svg.
    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
    [droidrefit-pcb-BOM-JLC.csv, droidrefit-pcb-BOM-full.csv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]
2026-09-05 PCB: fix J1 USB-C part - order C2894897 (matches the footprint), not C2765186
    The KiCad footprint USB_C_Receptacle_HCTL_HC-TYPE-C-16P-01A is drawn
    specifically for LCSC C2894897 (HCTL - the KiCad library cites its
    datasheet). The BOM was ordering C2765186 (SHOU HAN, a different brand)
    whose shield-tab / mounting-post geometry doesn't match -> J1 "doesn't
    line up with the holes" in JLC's assembly preview. Swapped J1 to C2894897.
    [droidrefit-pcb-BOM-JLC.csv, droidrefit-pcb-BOM-full.csv, droidrefit-pcb.kicad_sch]
2026-09-05 PCB: revert J1 back to C2765186
    C2894897 carries a JLC "difficult part" fee (needs an assembly fixture,
    flagged high difficulty). The J1 misalignment in JLC's preview is a CPL
    rotation-offset issue - part-independent, both LCSC parts show it - so
    there's no reason to eat the fee. Fix is the CPL rotation value.
    [droidrefit-pcb-BOM-JLC.csv, droidrefit-pcb-BOM-full.csv, droidrefit-pcb.kicad_sch]

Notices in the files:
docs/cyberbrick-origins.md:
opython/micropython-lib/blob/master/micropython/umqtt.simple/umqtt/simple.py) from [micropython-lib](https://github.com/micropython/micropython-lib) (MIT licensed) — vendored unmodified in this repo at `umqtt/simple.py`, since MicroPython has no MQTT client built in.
